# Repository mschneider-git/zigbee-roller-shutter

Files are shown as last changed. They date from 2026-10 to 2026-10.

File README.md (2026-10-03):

# Zigbee retrofit for a Heim & Haus solar roller shutter (ESP32-H2, Home Assistant ZHA)

Firmware and two PCB designs that add Zigbee to a battery/solar powered roller shutter drive
from **Heim & Haus**. The board plugs onto the 3-pin header of the membrane keypad and "presses"
the UP / DOWN keys electrically. The original controller stays untouched and keeps handling the
motor, its end switches and the solar charging. In Home Assistant the shutter shows up via
**ZHA** as a `cover` entity with open, close, stop and a position slider.

## Features

- Zigbee HA **Window Covering Device** (0x0202): up, down, stop, go to position (%)
- **Time-based position**, calculated from the measured travel times, reported while moving and
  stored in flash
- **Manual operation is tracked**: when someone presses a key on the drive, the firmware reads
  the key line and keeps the position in sync
- **Motor current and motor voltage sensing**: the battery voltage sag shows whether the motor
  really runs, the motor terminal voltage shows whether the controller switched it on. This
  detects the end positions and key presses that the controller took as "stop"
- **Battery and solar panel in Home Assistant**: battery voltage and charge level (battery sensor)
  and the solar panel voltage, measured every 15 minutes at rest
- **Low power**: Zigbee *sleepy end device* with light sleep between polls (peripherals powered
  down, 32 kHz crystal)
- **Zigbee OTA updates** through ZHA, with automatic rollback
- Factory reset: hold **BOOT for 5 s**

## The drive this was developed for

A **Heim & Haus solar roller shutter drive**: the motor, a controller box with a membrane keypad,
a battery pack and a solar panel. Everything below was measured on one of these drives. Other
drives with a similar keypad controller may work, but the travel times, the stop behaviour and the
voltage thresholds have to be checked.

| Controller box with its two keys | Opened: controller board, battery pack on the left |
|---|---|
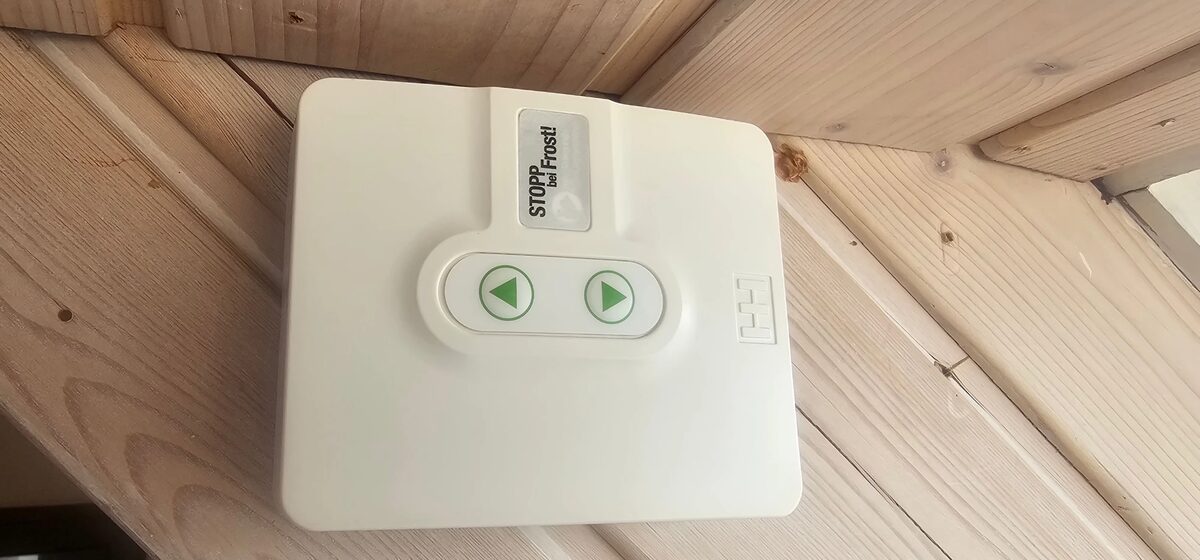
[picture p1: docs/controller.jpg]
Closed controller box with two arrow keys
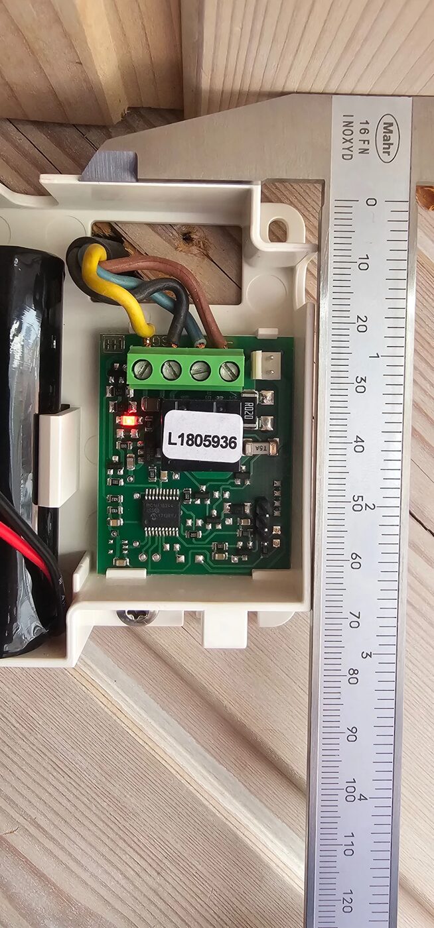
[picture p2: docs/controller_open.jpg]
Opened controller box with the original board
|  |  |

In the opened box: the 4-pole terminal block at the top (solar panel yellow/black, motor
blue/brown), the white battery plug top right, the relay and the `R020` shunt in the middle, the
PIC below it and the **3-pin keypad header bottom right**, which is where the carrier board plugs on.

| Part | Details |
|---|---|
| Controller | Microchip PIC16F18344 at 3.3 V (HT7533 regulator, about 100 mA, not used for the retrofit) |
| Motor switching | polarity reversal by relay, 20 mOhm shunt (`R020`) in battery−, fuse T5A |
| Terminals | **SG** solar panel (+ yellow, − black), **M** motor (+ blue, − brown), battery via plug (red = +) |
| Keypad | membrane keypad on a 3-pin header (GND · DOWN · UP), keys active low, see below |
| Battery | Cellonic CC-PA000942, 3S Li-ion, 11.1 V nominal, 2600 mAh (28.9 Wh), about 9–12.6 V |
| End positions | detected by the motor itself (it switches off internally) |

Measured behaviour of the controller:

| What | Value |
|---|---|
| Key press needed | 300 ms is enough for UP and DOWN |
| Travel time down / up | 14.2 s / 16.0 s (interrupted runs add up correctly) |
| Stop | press the **opposite** key while moving |
| Run-on after the end position | motor stays powered for about 30 s; a key press in that time is a stop |
| Battery voltage sag while running | 70–92 mV down, 140–200 mV up (battery at about 12.2 V) |
| Motor terminals at rest | both without voltage |
| Sleep of the controller | not observed: a key press after more than 5 min idle works immediately |

The controller sits in a small housing; the lid leaves about 22 mm above the original board, but
only about 6 mm above our carrier board at its left edge, which limits the height of the
H2-Zero (see the [carrier README](hardware/carrier/README.md)).

## How it works

The keypad keys of the original controller (a PIC16F18344 at 3.3 V) are active low with pull-ups
on the controller board. The ESP32-H2 drives the key lines open drain through 1 kOhm, so a
"key press" is just pulling the line low for 300 ms, exactly like the real keypad.

The controller stops a moving motor when the *opposite* key is pressed. After an end position it
keeps the motor powered for about 30 s (run-on); a press during that time acts as stop, not as
start. To handle this reliably the firmware measures:

| Signal | Divider | Used for |
|---|---|---|
| Battery+ | IO4 | motor current (voltage sag 70–200 mV while running), battery level |
| Motor terminal M+ / M− | IO5 / IO1 | controller switched the motor on (one terminal at battery voltage) |
| Solar panel | IO2 | reported to Home Assistant |

All dividers are 1 MOhm / 220 kOhm with 100 nF, about 10 µA from the battery.

**Only the battery and the keypad are required.** The motor terminal and solar inputs are optional
and can stay unconnected:

- Without the **motor terminals** the firmware relies on the battery voltage sag alone. It notices
  the missing terminals on the first move (motor current, but no terminal voltage) and remembers
  that. What is lost: a key press taken as stop during the run-on is only detected after the
  motor current timeout, and a move towards an end position where the shutter already is costs
  extra presses until the firmware gives up.
- Without the **solar panel** no solar voltage is reported to Home Assistant.

## Hardware

The [carrier board](hardware/carrier/README.md) (2 layers, 41.5 × 29.1 mm) plugs onto the keypad
header of the original board; the keypad itself plugs into a 90° header on the carrier, and the red
battery wire is cut and looped through a WAGO 2060 spring terminal. A **Waveshare ESP32-H2-Zero**
is soldered onto it on spacers (USB-C, BOOT and RESET are on the H2-Zero). Everything else
(regulator, protection, dividers, 32 kHz crystal) can be assembled by JLCPCB.

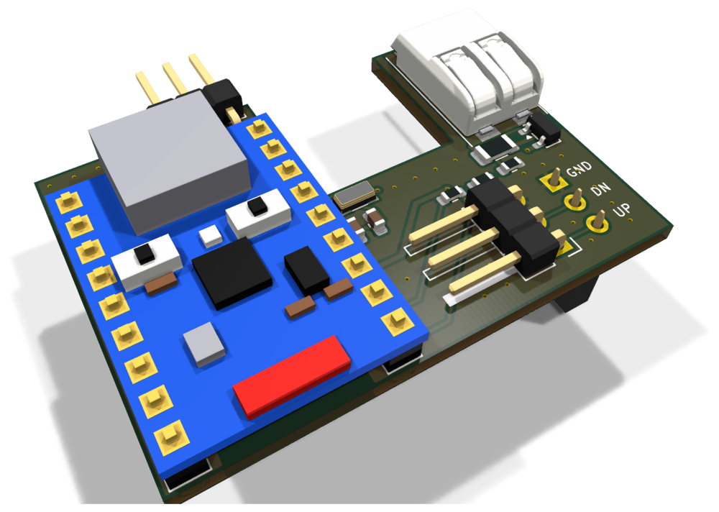
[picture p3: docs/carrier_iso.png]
3D render of the carrier board


*Render of the carrier board with the H2-Zero (simplified model) soldered on its pin headers.*

GPIO assignment (the firmware defaults):

| Function | GPIO |
|---|---|
| UP key / DOWN key | IO10 / IO11 |
| BOOT (factory reset) | IO9 |
| Dividers battery / M+ / M− / solar | IO4 / IO5 / IO1 / IO2 |
| 32 kHz crystal | IO13 / IO14 |

### Keypad header of the original board

| Pin (from the top) | Function | Level at rest |
|---|---|---|
| top | GND | 0 V |
| middle | DOWN | 3.3 V (pull-up on the controller board) |
| bottom | UP | 3.3 V (pull-up on the controller board) |

**Ground only comes via the keypad header.** Never connect battery− to our GND: the controller
has a 20 mOhm shunt between battery− and its ground, a second connection would bypass it.

## Building and flashing the firmware

Requires [ESP-IDF v6.1](https://docs.espressif.com/projects/esp-idf/en/v6.1/esp32h2/get-started/index.html).
The Zigbee library (esp-zigbee-lib 2.0.4) is fetched from the Espressif Component Registry on the
first build. Note that Espressif officially recommends ESP-IDF v5.5 for the Zigbee SDK.

```bash
idf.py set-target esp32h2
idf.py menuconfig        # "Roller shutter": travel times, GPIOs, stop method ...
idf.py build
idf.py -p /dev/ttyACM0 flash monitor
```

GitHub Actions builds the firmware on every push. `zigbee_roller_shutter_merged.bin` from the
workflow artifacts can be flashed at address `0x0`, e.g. with the
[ESP Web Flasher](https://espressif.github.io/esptool-js/).

## Configuration (menuconfig → Roller shutter)

| Option | Default | Meaning |
|---|---|---|
| Output stage | open drain | direct connection to the keypad lines (low = pressed); push-pull for optocouplers |
| Drive mode | PULSE | simulate a key press; the drive runs to the end position by itself |
| GPIO UP / DOWN | 10 / 11 | bottom / middle keypad pin |
| Stop method | opposite key | as measured on the Heim & Haus drive; alternatives: same key, dedicated key, none |
| Key press duration | 300 ms | |
| Detect manual key presses | on | key presses on the drive itself are tracked |
| Travel time up / down | 16.0 s / 14.2 s | measured on the drive |
| Dividers battery / M+ / M− / solar | GPIO 4 / 5 / 1 / 2 | −1 = not fitted. Unconnected motor terminals are detected on the first move, an unconnected solar input is not reported |
| Motor current via battery voltage | on | checks that the motor starts and detects the end position; time-based only without divider |
| Motor current step threshold | 50 mV | measured: 70–92 mV sag down, 140–200 mV up, noise ±10 mV |
| Motor voltage threshold | 6000 mV | both motor terminals are without voltage at rest |
| Battery empty / full | 9.6 V / 12.6 V | for the charge level (3S Li-ion, linear) |
| Measurement interval at rest | 900 s | battery and solar panel |
| Poll interval | 1000 ms | response time vs. current (end device), under *Roller shutter Zigbee* |

## Adding it to Home Assistant (ZHA)

1. Flash the firmware and install the board. A factory-new device searches for a network by itself.
2. In Home Assistant: *Settings → Devices & services → ZHA → Add device*.
3. The device appears as `DIY ESP32H2-Shutter` with a **cover** entity, a battery sensor and the
   solar voltage (Analog Input).
4. **Calibrate:** run the shutter fully up once. Every move into an end position resynchronises
   the calculated position.

To pair again: hold BOOT for 5 s (factory reset) or remove the device in ZHA.

## Firmware updates over Zigbee (OTA)

The first flash has to be done over USB because of the partition table (`ota_0` + `ota_1`).

**Increase the version:** `PROJECT_VER` in `CMakeLists.txt` (form `x.y.z`). It yields the OTA file
version (`1.2.3` → `0x01020300`, must increase with every update) and the version shown in ZHA.
Every build also produces `build/131B-5201-<version>-ota-file.zigbee`, which is also a CI artifact.

**Set up Home Assistant once** (`configuration.yaml`, then restart):

```yaml
zha:
  zigpy_config:
    ota:
      extra_providers:
        - type: advanced
          warning: "I understand I can *destroy* my devices by enabling OTA updates from files. Some OTA updates can be mistakenly applied to the wrong device, breaking it. I am consciously using this at my own risk."
          path: /config/zigpy_ota
```

**Install an update:** copy the `.zigbee` file to `/config/zigpy_ota`. The device asks for updates
at start-up and every 24 h; ZHA then shows an update entity. As a sleepy end device the download
takes about 10–20 minutes, then the device restarts.

**Safety net:** a new image only boots on trial. It becomes valid once it has rejoined the Zigbee
network; if it crashes before that, the next reset boots the previous version.

## Project status

- The control logic (key pulses, stop by opposite key, run-on handling, battery-sag detection)
  was developed and measured on the real drive with a bench setup.
- The ESP32-H2 boards have not been built and tested yet. Sleep current, OTA and the motor
  voltage sensing are untested on real hardware.
- Positions between the end positions are estimated from the travel times.

## Project structure

```
main/main.c                 Zigbee: device, commissioning, Window Covering commands -> shutter
main/ota.c                  Zigbee OTA client (download, rollback confirmation, periodic query)
main/ota_file_parser.c      parser for the Zigbee OTA file format (from the esp-zigbee-sdk example)
main/Kconfig.projbuild      Zigbee and OTA settings
tools/image_builder_tool.py creates the OTA file (from the esp-zigbee-sdk)
components/shutter/         roller shutter logic without Zigbee
  shutter.c                 state machine, key pulses, position tracking, NVS
  inputs.c                  BOOT button (factory reset) and detection of manual operation
  sense.c                   voltage sensing: battery, motor terminals, solar (ADC, own dividers)
  Kconfig                   roller shutter settings
hardware/carrier/           carrier board for the ESP32-H2-Zero (KiCad 10, generated by script)
hardware/lib/               project footprint and 3D model, their generator and the routing steps
hardware/fab.py             Gerber, BOM and placement files for JLCPCB
docs/                       photos of the original controller, renders of the carrier board
```

## License

[MIT](LICENSE), except for the following files taken from Espressif's
[esp-zigbee-sdk](https://github.com/espressif/esp-zigbee-sdk) examples, which are in the public
domain / CC0: `main/ota_file_parser.c`, `main/ota_file_parser.h`, `tools/image_builder_tool.py`.

The boards use footprints from the KiCad standard library (CC-BY-SA 4.0 with an exception that
allows their use in your own designs) and a footprint generated by `hardware/lib/make_footprints.py`.

This is an independent hobby project, not affiliated with Heim & Haus. Modifying the drive is at
your own risk: you are working on a battery-powered device with a motor.

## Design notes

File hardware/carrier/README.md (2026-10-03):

# Carrier board Roller-H2 Zero v2

2-layer board (41.5 × 29.1 mm, U-shaped) that plugs directly onto the 3-pin keypad header of the
original controller board. A **Waveshare ESP32-H2-Zero** sits on spacers above the regulator and
dividers and is soldered in by hand; JLCPCB can assemble everything else.

| Top | Bottom |
|---|---|
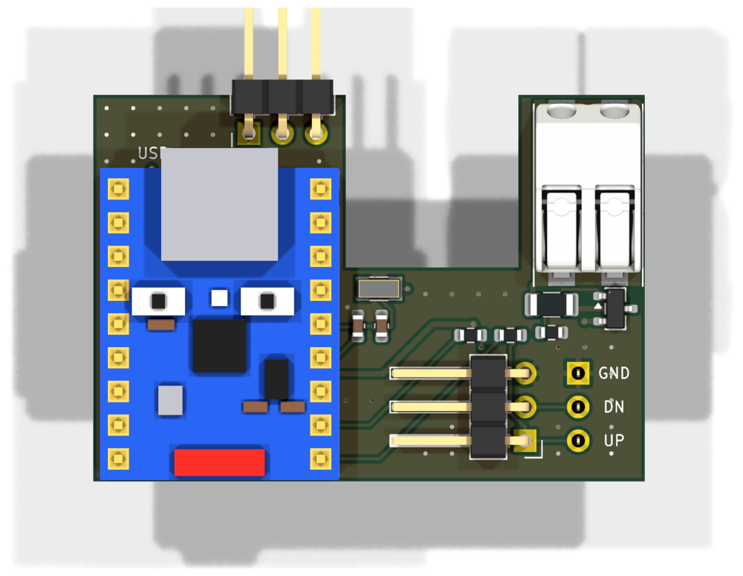
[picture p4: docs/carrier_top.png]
Carrier board, top side
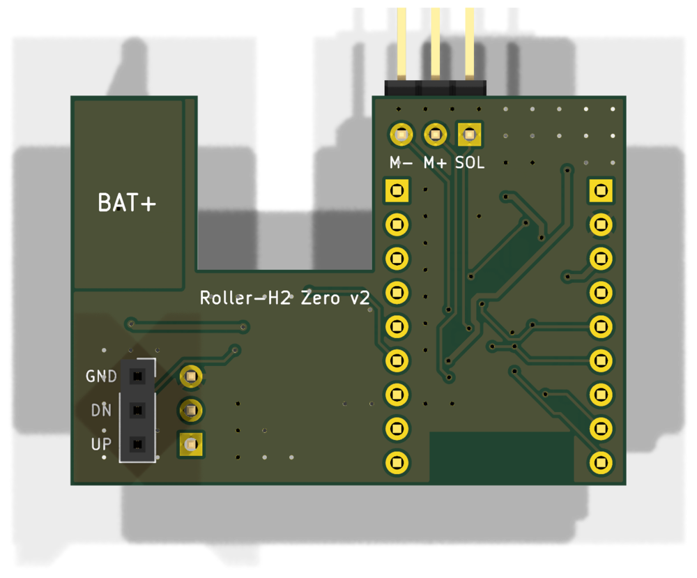
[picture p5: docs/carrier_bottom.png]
Carrier board, bottom side
|  |  |

The H2-Zero in the renders is a simplified model generated by `../lib/make_footprints.py`
from the product photos. For J1 the renders use WAGO's 3D model of the 2060-452/998-404 (from
WAGO's CAD download, not included here because of its terms of use); the board itself references
a simplified model of the terminal from the same script.

## Connectors

| Ref | What | Position |
|---|---|---|
| J6 / J7 | 1×9 holes for the H2-Zero (soldered by hand), **USB-C up**, antenna down | left |
| J3 | 1×3 socket, **bottom side**, onto the original keypad header (GND · DOWN · UP) | bottom right |
| J4 | 1×3 header, 90°, membrane keypad, pins towards the board centre, GND on top | bottom right |
| J1 | WAGO 2060-452, **battery+ looped through**: cut the red battery wire and put both ends into the two spring terminals | right arm, wire entry at the top |
| J5 | 1×3 header, 90°, measurement inputs **SOL · M+ · M−** (labels on the bottom side), **optional**, see below | left arm, pins pointing up |

USB-C, BOOT and RESET are on the H2-Zero itself.

## Circuit

USB-C, ESD protection, BOOT/RESET and the EN circuit are on the H2-Zero.

- **Battery+ (VBAT_RAW)** → PTC 100 mA (F1) → **reverse polarity protection** P-MOSFET AO3407A
  (Q1, gate via 100 kΩ to GND) → VBAT → 10 Ω (R1) → VIN.
  The two WAGO poles are connected by a copper area on both layers; the motor current only flows
  through this area, not through the electronics.
- **VIN**: TVS SMF13A (D1) against spikes from the motor, 10 µF (C1) → **TPS629203** (U1) → 3.3 V
  to the **3V3 pin** of the H2-Zero. VSET open = 3.3 V, MODE 64.9 kΩ = auto PFM/PWM 1 MHz,
  EN (pin 7) to VIN, PG open. The 5V pin of the H2-Zero stays open.
- **Dividers** 1 MΩ / 220 kΩ / 100 nF each (factor 5.55, 12.6 V → 2.27 V): battery (after the
  reverse polarity protection), motor+, motor−, solar.
- **Keys**: DOWN/UP each via 1 kΩ to the H2-Zero, connected 1:1 between J3 and J4.
- **32 kHz crystal** Y1 (CL 12.5 pF) with C11/C12 (18 pF each) on IO13/IO14.
- Regulator and dividers sit **below the H2-Zero**. There is no copper on either layer below its
  ceramic antenna (bottom end, at the board edge).
- Ground only via J3 (keypad GND). **Do not connect battery−** (20 mΩ shunt on the original board).

### GPIO assignment

Matches the firmware defaults:

| Signal | GPIO | Row / pin |
|---|---|---|
| Battery (divider) | IO4 | J6 / 8 |
| Motor+ (divider) | IO5 | J6 / 9 |
| Motor− (divider) | IO1 | J6 / 5 |
| Solar (divider) | IO2 | J6 / 6 |
| UP key | IO10 | J7 / 9 |
| DOWN key | IO11 | J7 / 8 |
| 32 kHz crystal | IO13 / IO14 | J7 / 6, 5 |
| 3V3 / GND | – | J6 / 3, 2 |

## Mounting the H2-Zero and height

The H2-Zero is soldered **directly into J6/J7** with its pin headers. The plastic strip of the
header (about 2.5 mm) acts as spacer: the regulator and dividers sit below it, the tallest part
is the inductor L1 at 1.2 mm.

- Height above the board: 2.5 mm spacer + 1 mm H2-Zero board + about 3.2 mm USB-C connector ≈ 6.7 mm.
- In the housing of the Heim & Haus controller there are only about 6 mm free above the board at the left edge.
  **Check before soldering** that the lid closes; if needed, shorten the plastic strip (leave at
  least 1.5 mm above L1).
- Cut the pins flush on the bottom side: J3 plugs onto the keypad header there.

## Preparing the H2-Zero

1. **Flash it before soldering** via its USB-C. Later, flash over USB only **without battery**
   (J1 open), otherwise its LDO and the TPS629203 feed the 3V3 rail at the same time. Further
   updates via Zigbee OTA.
2. **Remove the RGB LED (IO8)**: it draws 0.5–1 mA even when off.
3. The H2-Zero's LDO (ME6217) is back-fed via 3V3 and draws around 50 µA according to its
   datasheet. **Measure the sleep current**; if it is clearly too high, remove the LDO before
   soldering (USB flashing then only works with the battery connected, OTA is unaffected).

## Generating and checking

```bash
python3 make_board.py                         # placement, nets, silkscreen
python3 route.py /path/to/freerouting.jar     # Freerouting, GND areas, DRC (up to 5 attempts)
python3 ../fab.py carrier                     # fab/gerber.zip, bom_jlc.csv, cpl_jlc.csv
```

`route.py` always starts from a fresh `make_board.py`. Freerouting (2.x, needs Java) does not give
the same result on every run and occasionally hangs; the script checks every attempt with the DRC
and routes again up to five times. A run takes 2–7 minutes.

Expected: 0 DRC errors, 0 unconnected items. The remaining "silk_edge_clearance" warnings are
intended (header pins protrude over the edge).

## Ordering at JLCPCB

1. Upload `fab/gerber.zip`, 2 layers, 1.6 mm.
2. PCB Assembly (Economic), **Assembly side: Top**, `fab/bom_jlc.csv` and `fab/cpl_jlc.csv`.
   All parts are regular JLCPCB stock, no Global Sourcing needed. JLCPCB solders the 90° headers
   J4 and J5 (C92159) by hand. J3 (8.5 mm socket, C42431866) is in the BOM/CPL but sits on the
   **bottom side**: with "Assembly side: Top", JLCPCB leaves it out (Economic assembles one side only).
3. In the placement preview, check the rotation of **U1** (SOT-583, pin 1 = FB/VSET), **Q1**,
   **J1** (wire entry up), **J4** (pins towards the board centre) and **J5** (pins up).

## Assembly by hand

1. If J3 is not fitted: solder a 1×3 socket (8.5 mm) from the **bottom side**, opening away from
   the board. Plug it onto the keypad header of the original board to align it, then solder.
2. **Measure before soldering the H2-Zero**: battery on J1 → 3.3 V at J6 pin 3, ≈ 2.2 V at
   J6 pin 8 (IO4) with a 12.2 V battery.
3. Solder the H2-Zero (flashed, RGB LED removed) with its pin headers on spacers into J6/J7,
   **USB-C towards the "USB" label**. Cut the pins flush on the bottom side.
4. Cut the red battery wire, put both ends into J1, plug the board onto the keypad header and the
   keypad into J4.
5. Optional: connect J5 to the controller's terminal block, SOL to solar + (yellow), M+ and M− to
   the motor terminals (blue, brown). Without these wires the firmware works with the battery
   voltage alone (see the main README).

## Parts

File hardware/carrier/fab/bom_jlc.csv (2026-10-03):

Comment | Designator | Footprint | LCSC Part #
10u 25V | C1 | C_0805_2012Metric | C15850
100n | C10,C5,C7,C8,C9 | C_0603_1608Metric | C14663
18p | C11,C12 | C_0603_1608Metric | C1647
22u | C2 | C_0805_2012Metric | C784585
10u | C4 | C_0805_2012Metric | C15850
SMF13A | D1 | D_SOD-123F | C353315
PTC 100mA | F1 | Fuse_1206_3216Metric | C70065
WAGO 2060-452 battery+ | J1 | WAGO_2060-452 | C2765055
to keypad header | J3 | PinSocket_1x03_P2.54mm_Vertical | C42431866
Membrane keypad | J4 | PinHeader_1x03_P2.54mm_Horizontal | C92159
Solar M+ M- | J5 | PinHeader_1x03_P2.54mm_Horizontal | C92159
2.2u | L1 | L_1008_2520Metric | C237482
AO3407A | Q1 | SOT-23 | C15155
10 | R1 | R_0603_1608Metric | C22859
1M | R12,R14,R16,R18 | R_0603_1608Metric | C22935
220k | R13,R15,R17,R19 | R_0603_1608Metric | C22961
64.9k | R2 | R_0603_1608Metric | C2960807
100k | R5 | R_0603_1608Metric | C25803
1k | R8,R9 | R_0603_1608Metric | C21190
TPS629203DRLR | U1 | SOT-583-8 | C5219295
32.768k | Y1 | Crystal_SMD_3215-2Pin_3.2x1.5mm | C620155

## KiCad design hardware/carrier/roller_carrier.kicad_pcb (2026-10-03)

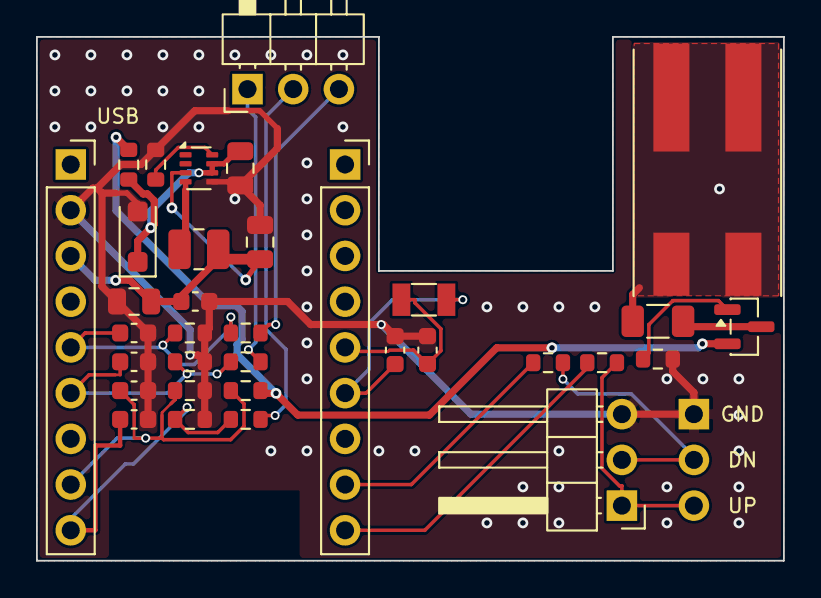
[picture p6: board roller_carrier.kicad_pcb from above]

Board: 2 copper layers, 41.5 x 29.1 mm, 35 parts (1 on the bottom side), 22 nets.

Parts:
C1: 10u 25V; C_0805_2012Metric
C2: 22u; C_0805_2012Metric
C4: 10u; C_0805_2012Metric
C5, C7, C8, C9, C10: 100n; C_0603_1608Metric
C11, C12: 18p; C_0603_1608Metric
D1: SMF13A; D_SOD-123F
F1: PTC 100mA; Fuse_1206_3216Metric
J1: WAGO 2060-452 battery+; WAGO_2060-452
J3: to keypad header; PinSocket_1x03_P2.54mm_Vertical
J4: Membrane keypad; PinHeader_1x03_P2.54mm_Horizontal
J5: Solar M+ M-; PinHeader_1x03_P2.54mm_Horizontal
J6: H2-Zero soldered left; PinSocket_1x09_P2.54mm_Vertical
J7: H2-Zero soldered right; PinSocket_1x09_P2.54mm_Vertical
L1: 2.2u; L_1008_2520Metric
Q1: AO3407A; SOT-23
R1: 10; R_0603_1608Metric
R2: 64.9k; R_0603_1608Metric
R5: 100k; R_0603_1608Metric
R8, R9: 1k; R_0603_1608Metric
R12, R14, R16, R18: 1M; R_0603_1608Metric
R13, R15, R17, R19: 220k; R_0603_1608Metric
U1: TPS629203DRLR; SOT-583-8
Y1: 32.768k; Crystal_SMD_3215-2Pin_3.2x1.5mm

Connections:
+3V3: C2.1, C4.1, C5.1, J6.3, L1.2, U1.3
ADC_BAT: C7.1, J6.8, R12.2, R13.1
ADC_MM: C9.1, J6.5, R16.2, R17.1
ADC_MP: C8.1, J6.9, R14.2, R15.1
ADC_SOL: C10.1, J6.6, R18.2, R19.1
DOWN: J3.2, J4.2, R8.2
GATE: Q1.1, R5.1
GND: C1.1, C2.2, C4.2, C5.2, C7.2, C8.2, C9.2, C10.2, C11.2, C12.2, D1.2, J3.1, J4.3, J6.2, R2.2, R5.2, R13.2, R15.2, R17.2, R19.2, U1.5
IO10: J7.9, R9.1
IO11: J7.8, R8.1
MM: J5.3, R16.1
MODE: R2.1, U1.8
MP: J5.2, R14.1
SOL: J5.1, R18.1
SW: L1.1, U1.4
UP: J3.3, J4.1, R9.2
VBAT: Q1.2, R1.2, R12.1
VBAT_F: F1.2, Q1.3
VBAT_RAW: F1.1, J1.1, J1.2
VIN: C1.2, D1.1, R1.1, U1.6, U1.7
XTAL_N: C12.1, J7.5, Y1.2
XTAL_P: C11.1, J7.6, Y1.1

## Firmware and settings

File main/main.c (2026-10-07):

/*
 * Zigbee roller shutter controller for Home Assistant (ZHA)
 *
 * Hardware: ESP32-H2 board (see hardware/) in parallel to the membrane keypad
 *           of a Heim & Haus solar roller shutter controller
 * Zigbee:   sleepy end device (battery powered),
 *           HA Window Covering Device (0x0202), endpoint 1
 *
 * ZHA recognises the device automatically as a "cover" entity (up / down /
 * stop / position). The position is calculated from time (see shutter.c).
 * In addition: battery voltage and charge level (Power Configuration) and the
 * solar panel voltage (Analog Input, in volts).
 */
#include <stdatomic.h>
#include <string.h>

#include "esp_app_desc.h"
#include "esp_check.h"
#include "esp_err.h"
#include "esp_log.h"
#include "esp_timer.h"
#include "freertos/FreeRTOS.h"
#include "freertos/task.h"
#include "nvs_flash.h"
#if CONFIG_PM_ENABLE
#include "esp_pm.h"
#include "esp_sleep.h"
#endif

#include "esp_zigbee.h"
#include "ezbee/zha.h"

#include "inputs.h"
#include "ota.h"
#include "shutter.h"

static const char *TAG = "MAIN";

#define SHUTTER_ENDPOINT                  1
#define ESP_ZIGBEE_STORAGE_PARTITION_NAME "nvs"

/* ZCL strings: first byte = length */
#define ZB_MANUFACTURER_NAME "\x03""DIY"
#define ZB_MODEL_IDENTIFIER  "\x0f""ESP32H2-Shutter"

static atomic_bool s_zb_ready;
static atomic_int  s_battery_mv = -1; /* last reading at rest, -1 = none */
static atomic_int  s_solar_mv   = -1;

/* ------------------------------------------------------------------------- */
/* Helpers                                                                   */
/* ------------------------------------------------------------------------- */

static esp_timer_handle_t       s_retry_timer;
static ezb_bdb_comm_mode_mask_t s_retry_mode;

static void retry_timer_cb(void *arg)
{
    esp_zigbee_lock_acquire(portMAX_DELAY);
    (void)ezb_bdb_start_top_level_commissioning(s_retry_mode);
    esp_zigbee_lock_release();
}

/** Restarts a commissioning step after a delay (call from the Zigbee context). */
static void schedule_commissioning(ezb_bdb_comm_mode_mask_t mode, uint32_t delay_ms)
{
    if (!s_retry_timer) {
        const esp_timer_create_args_t args = {
            .callback = retry_timer_cb,
            .name     = "zb_retry",
        };
        ESP_ERROR_CHECK(esp_timer_create(&args, &s_retry_timer));
    }
    esp_timer_stop(s_retry_timer);
    s_retry_mode = mode;
    ESP_ERROR_CHECK(esp_timer_start_once(s_retry_timer, (uint64_t)delay_ms * 1000));
}

/* ------------------------------------------------------------------------- */
/* Shutter -> Zigbee                                                         */
/* ------------------------------------------------------------------------- */

#define UNCHANGED_REPORT_DELAY_MS 1000

static esp_timer_handle_t s_report_timer;

/** Sends the position to the coordinator now, via the binding ZHA set up for reporting. */
static void report_timer_cb(void *arg)
{
    ezb_zcl_report_attr_cmd_t cmd = {
        .cmd_ctrl = {
            .dst_addr   = {.addr_mode = EZB_ADDR_MODE_NONE},
            .src_ep     = SHUTTER_ENDPOINT,
            .cluster_id = EZB_ZCL_CLUSTER_ID_WINDOW_COVERING,
            .manuf_code = EZB_ZCL_STD_MANUF_CODE,
            .fc         = {.direction = EZB_ZCL_CMD_DIRECTION_TO_CLI, .dis_default_rsp = 1},
        },
        .payload.attr_id = EZB_ZCL_ATTR_WINDOW_COVERING_CURRENT_POSITION_LIFT_PERCENTAGE_ID,
    };

    ESP_LOGI(TAG, "Position unchanged: reporting it");
    esp_zigbee_lock_acquire(portMAX_DELAY);
    ezb_err_t err = ezb_zcl_report_attr_cmd_req(&cmd);
    esp_zigbee_lock_release();
    if (err != EZB_ERR_NONE) {
        ESP_LOGW(TAG, "Reporting the position failed (%d)", err);
    }
}

static void shutter_state_changed(uint8_t lift_percent, shutter_motion_t motion)
{
    static const char *motion_str[] = {"stopped", "opening", "closing"};
    static int         published    = -1;

    ESP_LOGI(TAG, "Position %u %% (%s)", lift_percent, motion_str[motion]);
    if (!atomic_load(&s_zb_ready)) {
        return;
    }
    esp_zigbee_lock_acquire(portMAX_DELAY);
    ezb_zcl_status_t status = ezb_zcl_set_attr_value(SHUTTER_ENDPOINT, EZB_ZCL_CLUSTER_ID_WINDOW_COVERING,
                                                     EZB_ZCL_CLUSTER_SERVER,
                                                     EZB_ZCL_ATTR_WINDOW_COVERING_CURRENT_POSITION_LIFT_PERCENTAGE_ID,
                                                     EZB_ZCL_STD_MANUF_CODE, &lift_percent, false);
    esp_zigbee_lock_release();
    if (status != EZB_ZCL_STATUS_SUCCESS) {
        ESP_LOGW(TAG, "Setting the position failed (0x%02x)", status);
        return;
    }

    /* Reporting only sends changes. After a command that ends without a move (motor already at the
     * end switch, already at the target), ZHA would show "opening"/"closing" until its 5 min
     * timeout: send the unchanged position, which tells ZHA that the shutter stands still. ZHA only
     * sets "opening"/"closing" once the command's response has arrived, so wait for that first. */
    if (motion == SHUTTER_MOTION_STOPPED && lift_percent == published) {
        esp_timer_stop(s_report_timer);
        esp_timer_start_once(s_report_timer, UNCHANGED_REPORT_DELAY_MS * 1000);
    }
    published = lift_percent;
}

/* ------------------------------------------------------------------------- */
/* Battery and solar panel -> Zigbee                                         */
/* ------------------------------------------------------------------------- */

/** BatteryVoltage in 100 mV, 0xFF = unknown */
static uint8_t battery_voltage_attr(int mv)
{
    return (mv < 0) ? 0xFF : (uint8_t)((mv > 25400 ? 25400 : mv) / 100);
}

/** BatteryPercentageRemaining in 0.5 %, 0xFF = unknown */
static uint8_t battery_percent_attr(int mv)
{
    const int empty = CONFIG_SHUTTER_BATTERY_EMPTY_MV, full = CONFIG_SHUTTER_BATTERY_FULL_MV;

    if (mv < 0 || full <= empty) {
        return 0xFF;
    }
    if (mv <= empty) {
        return 0;
    }
    if (mv >= full) {
        return 200;
    }
    return (uint8_t)((mv - empty) * 200 / (full - empty));
}

static void set_attr(uint16_t cluster, uint16_t attr, void *value)
{
    ezb_zcl_status_t status = ezb_zcl_set_attr_value(SHUTTER_ENDPOINT, cluster, EZB_ZCL_CLUSTER_SERVER, attr,
                                                     EZB_ZCL_STD_MANUF_CODE, value, false);
    if (status != EZB_ZCL_STATUS_SUCCESS) {
        ESP_LOGW(TAG, "Attribute 0x%04x/0x%04x: error 0x%02x", cluster, attr, status);
    }
}

/** Writes the last reading to the attributes (reported to ZHA via reporting). */
static void power_publish(void)
{
    int     battery_mv = atomic_load(&s_battery_mv), solar_mv = atomic_load(&s_solar_mv);
    uint8_t voltage = battery_voltage_attr(battery_mv), percent = battery_percent_attr(battery_mv);

    esp_zigbee_lock_acquire(portMAX_DELAY);
    if (battery_mv >= 0) {
        set_attr(EZB_ZCL_CLUSTER_ID_POWER_CONFIG, EZB_ZCL_ATTR_POWER_CONFIG_BATTERY_VOLTAGE_ID, &voltage);
        set_attr(EZB_ZCL_CLUSTER_ID_POWER_CONFIG, EZB_ZCL_ATTR_POWER_CONFIG_BATTERY_PERCENTAGE_REMAINING_ID, &percent);
    }
    if (solar_mv >= 0) {
        float volts = (float)solar_mv / 1000.0f;
        set_attr(EZB_ZCL_CLUSTER_ID_ANALOG_INPUT, EZB_ZCL_ATTR_ANALOG_INPUT_PRESENT_VALUE_ID, &volts);
    }
    esp_zigbee_lock_release();
}

static void power_measured(int battery_mv, int solar_mv)
{
    atomic_store(&s_battery_mv, battery_mv);
    atomic_store(&s_solar_mv, solar_mv);
    if (atomic_load(&s_zb_ready)) {
        power_publish();
    }
}

/* ------------------------------------------------------------------------- */
/* Zigbee -> shutter                                                         */
/* ------------------------------------------------------------------------- */

static void window_covering_movement_handler(ezb_zcl_window_covering_movement_message_t *message)
{
    ESP_RETURN_ON_FALSE(message && message->in.header, , TAG, "empty movement message");

    message->out.result = EZB_ZCL_STATUS_SUCCESS;
    if (message->info.dst_ep != SHUTTER_ENDPOINT) {
        return;
    }

    switch (message->in.header->cmd_id) {
    case EZB_ZCL_CMD_WINDOW_COVERING_UP_OPEN_ID:
        ESP_LOGI(TAG, "Zigbee: up");
        shutter_open();
        break;
    case EZB_ZCL_CMD_WINDOW_COVERING_DOWN_CLOSE_ID:
        ESP_LOGI(TAG, "Zigbee: down");
        shutter_close();
        break;
    case EZB_ZCL_CMD_WINDOW_COVERING_STOP_ID:
        ESP_LOGI(TAG, "Zigbee: stop");
        shutter_stop();
        break;
    case EZB_ZCL_CMD_WINDOW_COVERING_GO_TO_LIFT_PERCENTAGE_ID:
        ESP_LOGI(TAG, "Zigbee: go to %u %%", message->in.payload.lift_percentage);
        if (message->in.payload.lift_percentage > 100) {
            message->out.result = EZB_ZCL_STATUS_INVALID_VALUE;
        } else {
            shutter_go_to_percent(message->in.payload.lift_percentage);
        }
        break;
    default:
        ESP_LOGW(TAG, "Unsupported Window Covering command 0x%02x", message->in.header->cmd_id);
        message->out.result = EZB_ZCL_STATUS_UNSUP_CMD;
        break;
    }
}

static void zcl_core_action_handler(ezb_zcl_core_action_callback_id_t callback_id, void *message)
{
    switch (callback_id) {
    case EZB_ZCL_CORE_WINDOW_COVERING_MOVEMENT_CB_ID:
        window_covering_movement_handler((ezb_zcl_window_covering_movement_message_t *)message);
        break;
    case EZB_ZCL_CORE_SET_ATTR_VALUE_CB_ID:
        /* e.g. identify time; not relevant for the shutter */
        break;
    default:
        if (!ota_handle_action(callback_id, message)) {
            ESP_LOGD(TAG, "ZCL Core Action: ID(0x%04lx)", (unsigned long)callback_id);
        }
        break;
    }
}

/* ------------------------------------------------------------------------- */
/* Zigbee network                                                            */
/* ------------------------------------------------------------------------- */

static bool app_signal_handler(const ezb_app_signal_t *app_signal)
{
    ezb_app_signal_type_t signal_type = ezb_app_signal_get_type(app_signal);

    switch (signal_type) {
    case EZB_ZDO_SIGNAL_SKIP_STARTUP:
        ESP_LOGI(TAG, "Initialising the Zigbee stack");
        ezb_bdb_start_top_level_commissioning(EZB_BDB_MODE_INITIALIZATION);
        break;
    case EZB_BDB_SIGNAL_DEVICE_FIRST_START:
    case EZB_BDB_SIGNAL_DEVICE_REBOOT: {
        ezb_bdb_comm_status_t status = *((ezb_bdb_comm_status_t *)ezb_app_signal_get_params(app_signal));
        if (status == EZB_BDB_STATUS_SUCCESS) {
            if (ezb_bdb_is_factory_new()) {
                ESP_LOGI(TAG, "Factory new - searching for a Zigbee network to join (enable pairing in ZHA!)");
                ezb_bdb_start_top_level_commissioning(EZB_BDB_MODE_NETWORK_STEERING);
            } else {
                ESP_LOGI(TAG, "Reboot - already joined to a network");
                ota_network_ready();
            }
        } else {
            ESP_LOGW(TAG, "%s failed (0x%02x), retrying", ezb_app_signal_to_string(signal_type), status);
            schedule_commissioning(EZB_BDB_MODE_INITIALIZATION, 1000);
        }
    } break;
    case EZB_BDB_SIGNAL_STEERING: {
        ezb_bdb_comm_status_t status = *((ezb_bdb_comm_status_t *)ezb_app_signal_get_params(app_signal));
        if (status == EZB_BDB_STATUS_SUCCESS) {
            ezb_extpanid_t extended_pan_id;
            ezb_nwk_get_extended_panid(&extended_pan_id);
            ESP_LOGI(TAG, "Joined network: PAN ID 0x%04hx (EXT 0x%llx), channel %d, address 0x%04hx",
                     ezb_nwk_get_panid(), extended_pan_id.u64, ezb_nwk_get_current_channel(),
                     ezb_nwk_get_short_address());
            ota_network_ready();
        } else {
            ESP_LOGI(TAG, "No network found (0x%02x), retrying in 5 s", status);
            schedule_commissioning(EZB_BDB_MODE_NETWORK_STEERING, 5000);
        }
    } break;
    case EZB_ZDO_SIGNAL_LEAVE: {
        const ezb_zdo_signal_leave_params_t *leave_params = ezb_app_signal_get_params(app_signal);
        ESP_LOGW(TAG, "Left the network (type 0x%02x)", leave_params->leave_type);
        if (leave_params->leave_type == EZB_ZDO_LEAVE_TYPE_RESET) {
            /* e.g. removed in ZHA: be ready for pairing again right away */
            schedule_commissioning(EZB_BDB_MODE_NETWORK_STEERING, 1000);
        }
    } break;
    default:
        ESP_LOGI(TAG, "Zigbee Signal: %s (0x%02x)", ezb_app_signal_to_string(signal_type), signal_type);
        break;
    }
    return true;
}

static esp_err_t create_window_covering_device(void)
{
    ezb_af_device_desc_t             dev_desc = ezb_af_create_device_desc();
    ezb_zha_window_covering_config_t cfg      = EZB_ZHA_WINDOW_COVERING_CONFIG();

    cfg.basic_cfg.power_source = EZB_ZCL_BASIC_POWER_SOURCE_BATTERY;
    cfg.window_covering_cfg.window_covering_type = EZB_ZCL_WINDOW_COVERING_WINDOW_COVERING_TYPE_ROLLERSHADE;
    cfg.window_covering_cfg.config_status =
        EZB_ZCL_WINDOW_COVERING_CONFIG_STATUS_OPERATIONAL | EZB_ZCL_WINDOW_COVERING_CONFIG_STATUS_ONLINE;

    ezb_af_ep_desc_t ep_desc = ezb_zha_create_window_covering(SHUTTER_ENDPOINT, &cfg);

    ezb_zcl_cluster_desc_t basic_desc =
        ezb_af_endpoint_get_cluster_desc(ep_desc, EZB_ZCL_CLUSTER_ID_BASIC, EZB_ZCL_CLUSTER_SERVER);
    ezb_zcl_basic_cluster_desc_add_attr(basic_desc, EZB_ZCL_ATTR_BASIC_MANUFACTURER_NAME_ID,
                                        (void *)ZB_MANUFACTURER_NAME);
    ezb_zcl_basic_cluster_desc_add_attr(basic_desc, EZB_ZCL_ATTR_BASIC_MODEL_IDENTIFIER_ID,
                                        (void *)ZB_MODEL_IDENTIFIER);
    /* Version from PROJECT_VER (CMakeLists.txt), ZCL string with length byte, max. 16 characters */
    static char sw_build_id[17];
    const char *version = esp_app_get_description()->version;
    sw_build_id[0]      = (char)strnlen(version, sizeof(sw_build_id) - 1);
    memcpy(&sw_build_id[1], version, (size_t)sw_build_id[0]);
    ezb_zcl_basic_cluster_desc_add_attr(basic_desc, EZB_ZCL_ATTR_BASIC_SW_BUILD_ID_ID, sw_build_id);

    /* Optional attribute for the position in percent - read and reported by ZHA */
    uint8_t lift_percent = shutter_get_percent();
    ezb_zcl_cluster_desc_t wc_desc =
        ezb_af_endpoint_get_cluster_desc(ep_desc, EZB_ZCL_CLUSTER_ID_WINDOW_COVERING, EZB_ZCL_CLUSTER_SERVER);
    ESP_RETURN_ON_FALSE(wc_desc, ESP_FAIL, TAG, "window covering cluster missing");
    ezb_zcl_window_covering_cluster_desc_add_attr(
        wc_desc, EZB_ZCL_ATTR_WINDOW_COVERING_CURRENT_POSITION_LIFT_PERCENTAGE_ID, &lift_percent);

    /* Battery: voltage and charge level, ZHA creates a battery sensor for it */
    ezb_zcl_cluster_desc_t power_desc = ezb_zcl_power_config_create_cluster_desc(NULL, EZB_ZCL_CLUSTER_SERVER);
    ESP_RETURN_ON_FALSE(power_desc, ESP_FAIL, TAG, "power config cluster failed");
    uint8_t battery_voltage = battery_voltage_attr(atomic_load(&s_battery_mv));
    uint8_t battery_percent = battery_percent_attr(atomic_load(&s_battery_mv));
    uint8_t battery_size    = EZB_ZCL_POWER_CONFIG_BATTERY_SIZE_OTHER;
    ezb_zcl_power_config_cluster_desc_add_attr(power_desc, EZB_ZCL_ATTR_POWER_CONFIG_BATTERY_VOLTAGE_ID,
                                               &battery_voltage);
    ezb_zcl_power_config_cluster_desc_add_attr(power_desc, EZB_ZCL_ATTR_POWER_CONFIG_BATTERY_PERCENTAGE_REMAINING_ID,
                                               &battery_percent);
    ezb_zcl_power_config_cluster_desc_add_attr(power_desc, EZB_ZCL_ATTR_POWER_CONFIG_BATTERY_SIZE_ID, &battery_size);
    /* ZCL defines BatteryVoltage as not reportable, so ZHA's reporting configuration for it fails
     * (UNREPORTABLE_ATTRIBUTE) and the value only changes when ZHA polls: allow reporting */
    ezb_zcl_attr_desc_t voltage_attr = ezb_zcl_cluster_get_attr_desc(
        power_desc, EZB_ZCL_ATTR_POWER_CONFIG_BATTERY_VOLTAGE_ID, EZB_ZCL_STD_MANUF_CODE);
    ESP_RETURN_ON_FALSE(voltage_attr != EZB_INVALID_ZCL_ATTR_DESC, ESP_FAIL, TAG, "battery voltage attribute missing");
    ezb_zcl_attr_desc_set_access(voltage_attr,
                                 ezb_zcl_attr_desc_get_access(voltage_attr) | EZB_ZCL_ATTR_ACCESS_REPORTING);
    ESP_RETURN_ON_ERROR(ezb_af_endpoint_add_cluster_desc(ep_desc, power_desc), TAG, "add power config failed");

    /* Solar panel: voltage in volts */
    int solar_mv = atomic_load(&s_solar_mv);
    ezb_zcl_analog_input_cluster_server_config_t solar_cfg = {
        .out_of_service = false,
        .present_value  = solar_mv < 0 ? 0.0f : (float)solar_mv / 1000.0f,
        .status_flags   = EZB_ZCL_ANALOG_INPUT_STATUS_FLAGS_DEFAULT_VALUE,
    };
    ezb_zcl_cluster_desc_t solar_desc = ezb_zcl_analog_input_create_cluster_desc(&solar_cfg, EZB_ZCL_CLUSTER_SERVER);
    ESP_RETURN_ON_FALSE(solar_desc, ESP_FAIL, TAG, "analog input cluster failed");
    ezb_zcl_analog_input_cluster_desc_add_attr(solar_desc, EZB_ZCL_ATTR_ANALOG_INPUT_DESCRIPTION_ID,
                                               (void *)"\x0a""Solar Volt");
    /* ZHA only creates the sensor if the unit is known as well (BACnet engineering unit 5 = volts) */
    uint16_t solar_units = 5;
    ezb_zcl_analog_input_cluster_desc_add_attr(solar_desc, EZB_ZCL_ATTR_ANALOG_INPUT_ENGINEERING_UNITS_ID,
                                               &solar_units);
    ESP_RETURN_ON_ERROR(ezb_af_endpoint_add_cluster_desc(ep_desc, solar_desc), TAG, "add analog input failed");

    ESP_RETURN_ON_ERROR(ota_add_client_cluster(ep_desc, SHUTTER_ENDPOINT), TAG, "OTA cluster failed");

    ESP_RETURN_ON_ERROR(ezb_af_device_add_endpoint_desc(dev_desc, ep_desc), TAG, "add endpoint failed");
    ESP_RETURN_ON_ERROR(ezb_af_device_desc_register(dev_desc), TAG, "register device failed");
    ota_after_register();

    ezb_zcl_core_action_handler_register(zcl_core_action_handler);
    return ESP_OK;
}

static void factory_reset(void)
{
    esp_zigbee_lock_acquire(portMAX_DELAY);
    esp_zigbee_factory_reset(); /* erases the Zigbee data and restarts */
}

static void zigbee_task(void *pvParameters)
{
    esp_zigbee_config_t config = {
        .device_config =
            {
                .device_type         = EZB_NWK_DEVICE_TYPE_END_DEVICE,
                .install_code_policy = false,
                .zed_config =
                    {
                        .ed_timeout = EZB_NWK_ED_TIMEOUT_64MIN,
                        .keep_alive = CONFIG_SHUTTER_ZB_POLL_INTERVAL_MS,
                    },
            },
        .platform_config =
            {
                .storage_partition_name = ESP_ZIGBEE_STORAGE_PARTITION_NAME,
                .radio_config =
                    {
                        .radio_mode = ESP_ZIGBEE_RADIO_MODE_NATIVE,
                    },
            },
    };

    ESP_ERROR_CHECK(esp_zigbee_init(&config));
    ESP_ERROR_CHECK(ezb_bdb_set_primary_channel_set(CONFIG_SHUTTER_ZB_CHANNEL_MASK));
    ESP_ERROR_CHECK(ezb_bdb_set_secondary_channel_set(CONFIG_SHUTTER_ZB_CHANNEL_MASK));
    ESP_ERROR_CHECK(ezb_app_signal_add_handler(app_signal_handler));
    /* Sleepy end device: radio off between polls */
    ezb_nwk_set_rx_on_when_idle(false);
    /* Battery powered: the node descriptor otherwise reports constant (mains) power, and ZHA then
     * creates no battery sensor and uses the shorter availability timeout for mains devices */
    ezb_af_node_power_desc_t power_desc = {
        .current_power_mode         = EZB_AF_NODE_POWER_MODE_COME_ON_PERIODICALLY,
        .available_power_sources    = EZB_AF_NODE_POWER_SOURCE_RECHARGEABLE_BATTERY,
        .current_power_source       = EZB_AF_NODE_POWER_SOURCE_RECHARGEABLE_BATTERY,
        .current_power_source_level = EZB_AF_NODE_POWER_SOURCE_LEVEL_100_PERCENT,
    };
    ESP_ERROR_CHECK(ezb_af_set_node_power_desc(&power_desc));
    ESP_ERROR_CHECK(create_window_covering_device());
    atomic_store(&s_zb_ready, true);
    power_publish(); /* a reading that finished between creating the clusters and now */

    ESP_ERROR_CHECK(esp_zigbee_start(false));
    esp_zigbee_launch_mainloop();

    esp_zigbee_deinit();
    vTaskDelete(NULL);
}

#if CONFIG_PM_ENABLE
static esp_err_t power_save_init(void)
{
    esp_pm_config_t pm_config = {
        .max_freq_mhz       = CONFIG_ESP_DEFAULT_CPU_FREQ_MHZ,
        .min_freq_mhz       = CONFIG_ESP_DEFAULT_CPU_FREQ_MHZ,
        .light_sleep_enable = true,
    };
    ESP_RETURN_ON_ERROR(esp_pm_configure(&pm_config), TAG, "esp_pm_configure failed");
    /* Keys (reset, manual operation) wake from light sleep; with the peripherals
     * powered down, EXT1 takes over (inputs.c) */
#if !CONFIG_PM_POWER_DOWN_PERIPHERAL_IN_LIGHT_SLEEP
    ESP_RETURN_ON_ERROR(esp_sleep_enable_gpio_wakeup(), TAG, "gpio wakeup failed");
#endif
    return ESP_OK;
}
#endif

void app_main(void)
{
    esp_err_t err = nvs_flash_init();
    if (err == ESP_ERR_NVS_NO_FREE_PAGES || err == ESP_ERR_NVS_NEW_VERSION_FOUND) {
        ESP_ERROR_CHECK(nvs_flash_erase());
        err = nvs_flash_init();
    }
    ESP_ERROR_CHECK(err);
#if CONFIG_PM_ENABLE
    ESP_ERROR_CHECK(power_save_init());
#endif

    const esp_timer_create_args_t report_timer_args = {
        .callback = report_timer_cb,
        .name     = "zb_report",
    };
    ESP_ERROR_CHECK(esp_timer_create(&report_timer_args, &s_report_timer));

    shutter_set_power_cb(power_measured);
    ESP_ERROR_CHECK(shutter_init(shutter_state_changed));
    ESP_ERROR_CHECK(inputs_init(factory_reset));

    ESP_LOGI(TAG, "Starting the Zigbee stack");
    xTaskCreate(zigbee_task, "zigbee_main", 6144, NULL, 5, NULL);
}

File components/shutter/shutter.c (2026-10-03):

/*
 * Roller shutter drive with time-based position tracking.
 *
 * All state changes happen exclusively in the module's own FreeRTOS task.
 * Other tasks (Zigbee, key detection) only send commands through a queue.
 * When idle the task blocks completely so the chip can sleep.
 *
 * With CONFIG_SHUTTER_BATTERY_SENSE the motor current is detected from the
 * sag of the battery voltage: after each key press the firmware checks that
 * the motor starts (otherwise it presses again, e.g. because the controller
 * keeps running for about 30 s after an end position and takes the press as
 * stop), and the end position is detected when the motor switches off.
 *
 * If both motor terminals are connected as well, their voltage shows directly
 * whether the controller switched the motor on: a key press taken as stop is
 * detected immediately, as is a move to an end position where the shutter
 * already is (voltage, but no motor current). Unconnected terminals are
 * learned on the first move (see volt_init()).
 *
 * At rest the battery and the solar panel are measured every
 * CONFIG_SHUTTER_MONITOR_INTERVAL_S seconds and reported via shutter_set_power_cb().
 */
#include <stdatomic.h>
#include <stdlib.h>

#include "driver/gpio.h"
#include "esp_check.h"
#include "esp_log.h"
#include "esp_timer.h"
#include "freertos/FreeRTOS.h"
#include "freertos/queue.h"
#include "freertos/task.h"
#include "nvs.h"
#if CONFIG_PM_ENABLE
#include "esp_pm.h"
#endif

#include "sense.h"
#include "shutter.h"

static const char *TAG = "SHUTTER";

/* Internal position in 1/1000 percent: 0 = open, POS_MAX = closed */
#define POS_MAX     100000
#define POS_PER_PCT (POS_MAX / 100)
#define TICK_MS     50

#define NVS_NAMESPACE "shutter"
#define NVS_KEY_POS   "pos"
#define NVS_KEY_VOLT  "volt_absent"

#if CONFIG_SHUTTER_OUTPUT_OPEN_DRAIN
#define LEVEL_ON        0
#define LEVEL_OFF       1 /* open drain: 1 = high impedance */
#define OUTPUT_GPIO_MODE GPIO_MODE_INPUT_OUTPUT_OD
#else
#define LEVEL_ON        1
#define LEVEL_OFF       0
#define OUTPUT_GPIO_MODE GPIO_MODE_OUTPUT
#endif

#if CONFIG_SHUTTER_OUTPUT_MODE_HOLD
#define OUTPUT_MODE_STR "HOLD"
#else
#define OUTPUT_MODE_STR "PULSE"
#endif

typedef enum {
    CMD_GOTO,
    CMD_STOP,
    CMD_MANUAL_OPEN,
    CMD_MANUAL_CLOSE,
    CMD_MANUAL_STOP,
} shutter_cmd_type_t;

typedef struct {
    shutter_cmd_type_t type;
    int32_t            target; /* CMD_GOTO: position units */
} shutter_cmd_t;

typedef enum {
    PHASE_IDLE,    /* motor stopped */
    PHASE_PAUSE,   /* motor stopped, waiting before reversing */
    PHASE_MOVING,  /* motor moving towards the target */
    PHASE_OVERRUN, /* end position reached by calculation, safety margin */
} shutter_phase_t;

static QueueHandle_t      s_queue;
static shutter_state_cb_t s_state_cb;
static shutter_power_cb_t s_power_cb;
static atomic_uint        s_percent_cache;
static atomic_ullong      s_driving_mask; /* GPIOs currently being driven */
#if CONFIG_PM_ENABLE
static esp_pm_lock_handle_t s_pm_lock;
static bool                 s_pm_locked;
#endif

/* Only used in the shutter task */
static int32_t          s_pos;
static int32_t          s_target;
static shutter_motion_t s_motion = SHUTTER_MOTION_STOPPED;
static shutter_phase_t  s_phase  = PHASE_IDLE;
static int64_t          s_last_update_us;
static int64_t          s_phase_until_us;
static int64_t          s_last_report_us;
static uint8_t          s_last_reported_pct    = 0xFF;
static shutter_motion_t s_last_reported_motion = (shutter_motion_t)0xFF;

static inline uint8_t pos_to_pct(int32_t pos)
{
    return (uint8_t)((pos + POS_PER_PCT / 2) / POS_PER_PCT);
}

static inline bool is_end_position(int32_t pos)
{
    return pos <= 0 || pos >= POS_MAX;
}

/* ------------------------------------------------------------------------- */
/* Power saving: no light sleep while moving (outputs + timing)            */
/* ------------------------------------------------------------------------- */

static void pm_keep_awake(bool awake)
{
#if CONFIG_PM_ENABLE
    if (awake && !s_pm_locked) {
        esp_pm_lock_acquire(s_pm_lock);
        s_pm_locked = true;
    } else if (!awake && s_pm_locked) {
        sense_release(); /* the ADC registers do not survive sleep */
        esp_pm_lock_release(s_pm_lock);
        s_pm_locked = false;
    }
#else
    (void)awake;
#endif
}

/* ------------------------------------------------------------------------- */
/* Outputs                                                                   */
/* ------------------------------------------------------------------------- */

static void output_set(int gpio, bool on)
{
    if (gpio < 0) {
        return;
    }
    if (on) {
        atomic_fetch_or(&s_driving_mask, 1ULL << gpio);
        gpio_set_level(gpio, LEVEL_ON);
    } else {
        gpio_set_level(gpio, LEVEL_OFF);
        /* Only read the line as input again once it has safely gone high */
        vTaskDelay(pdMS_TO_TICKS(30));
        atomic_fetch_and(&s_driving_mask, ~(1ULL << gpio));
    }
}

#if CONFIG_SHUTTER_OUTPUT_MODE_PULSE
static void output_pulse(int gpio)
{
    output_set(gpio, true);
    vTaskDelay(pdMS_TO_TICKS(CONFIG_SHUTTER_PULSE_MS));
    output_set(gpio, false);
}
#endif

/* ------------------------------------------------------------------------- */
/* Motor current from the battery voltage                                    */
/* ------------------------------------------------------------------------- */

#if CONFIG_SHUTTER_BATTERY_SENSE && CONFIG_SHUTTER_OUTPUT_MODE_PULSE
#define MOTOR_SENSE 1
#else
#define MOTOR_SENSE 0
#endif

#if MOTOR_SENSE
#define SENSE_SAMPLES      10   /* one block: 10 x 10 ms */
#define SENSE_SAMPLE_MS    10
#define SENSE_CONFIRM      3    /* a step must last 3 blocks (about 300 ms) */
#define SENSE_END_GRACE_MS 5000 /* at the end position, wait longer for the switch-off */

static bool s_sense_ok;   /* divider connected, voltage plausible */
static int  s_run_mv;     /* battery voltage while moving (tracked) */
static int  s_rise_count; /* consecutive blocks above the running level */

/** Average over one block (about 100 ms), -1 on error. */
static int sense_block(void)
{
    int32_t sum = 0;

    for (int i = 0; i < SENSE_SAMPLES; i++) {
        int mv;
        if (sense_read_mv(SENSE_BATTERY, 4, &mv) != ESP_OK) {
            return -1;
        }
        sum += mv;
        vTaskDelay(pdMS_TO_TICKS(SENSE_SAMPLE_MS));
    }
    return (int)(sum / SENSE_SAMPLES);
}

/** Idle level before a key press; also checks whether there is a reading at all. */
static int sense_idle(void)
{
    if (!sense_available(SENSE_BATTERY)) {
        s_sense_ok = false;
        return -1;
    }
    int mv = sense_block();

    s_sense_ok = mv >= CONFIG_SHUTTER_BATTERY_MIN_MV;
    if (!s_sense_ok) {
        ESP_LOGW(TAG, "Battery voltage implausible (%d mV), time-based only", mv);
    }
    return mv;
}
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

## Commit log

2026-10-03 Zigbee retrofit for a Heim & Haus solar roller shutter
    ESP32-H2 firmware (ESP-IDF, esp-zigbee-lib) that controls the drive
    through its membrane keypad header and appears in Home Assistant ZHA as a
    cover with battery and solar voltage, plus a carrier board for the
    Waveshare ESP32-H2-Zero (KiCad 10, generated by script).
    [bom_jlc.csv, partitions.csv, roller_carrier.kicad_pcb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]
2026-10-03 Detect unconnected motor terminal and solar inputs
    The motor terminal and solar inputs read 0 V when left open, the same as
    at rest or at night, so the firmware used to assume a motor that never
    switched on and pressed the key three times.
    - Motor terminals: if the battery voltage shows the motor running while
    the terminals stay at 0 V, motor voltage sensing is switched off and
    this is stored in NVS. A later start that sees the voltage turns it on
    again.
    - Solar: the voltage is only reported once the panel has seen light
    (above 1 V) and not after two days without.
    - Document that J5 (SOL, M+, M-) is optional; Kconfig help no longer
    refers to two boards.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
    [shutter.c]
2026-10-06 Report battery power and the solar voltage unit to ZHA
    - Node power descriptor set to a rechargeable battery (receiver on
    periodically). Without it the node descriptor reported mains power, so
    ZHA created no battery sensor and used the mains availability timeout.
    - Analog Input "Solar Volt" gets engineering units 5 (volts); ZHA only
    creates the sensor when a unit is known.
    Same fix as in the replacement controller firmware, where it was tested
    with ZHA on an ESP32-H2-Zero.
    [main.c]
2026-10-07 Report an unchanged position after a command without a move
    Reporting only sends changes. When a command ends without a move (motor
    already at the end switch, already at the target), ZHA kept showing
    "opening"/"closing" until its 5 min timeout. Send the unchanged position
    explicitly, 1 s after the stop so that ZHA has processed the command's
    response first; an immediate report often arrived before it and was
    overridden.
2026-10-07 Make BatteryVoltage reportable
    ZCL defines BatteryVoltage as not reportable, so ZHA's reporting
    configuration for it failed with UNREPORTABLE_ATTRIBUTE and the voltage
    only changed when ZHA polled. Set the reporting access flag on the
    attribute.
    [main.c]
